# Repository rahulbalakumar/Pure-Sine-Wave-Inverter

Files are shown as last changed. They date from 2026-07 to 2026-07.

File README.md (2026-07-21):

# 300W Pure Sine Wave Inverter - Final Project Repository

## 📋 Table of Contents
1. [Project Overview](#project-overview)
2. [Team Members](#team-members)
3. [Problem Statement & Motivation](#problem-statement--motivation)
4. [Technical Architecture](#technical-architecture)
5. [PCB Design & Schematics](#pcb-design--schematics)
6. [Simulations & Verification](#simulations--verification)
7. [Enclosure & Mechanical Design](#enclosure--mechanical-design)
8. [Bill of Quantities (BOQ) & Costing](#bill-of-quantities-boq--costing)
9. [Manufacturing Considerations](#manufacturing-considerations)
10. [Marketing & Competitor Landscape](#marketing--competitor-landscape)
11. [Future Improvements](#future-improvements)

---

## 🏛️ Project Overview
This repository contains the complete documentation, design files, schematics, simulations, and manufacturing reports for the **300W Pure Sine Wave Inverter** developed by **Group Forge** for the module **EN2160 - Electronic Design Realization** at the Department of Electronic and Telecommunication Engineering, **University of Moratuwa, Sri Lanka**.

The device is engineered to provide clean, grid-quality AC power (230V, 50Hz) from a 12V battery source during power outages, specifically tailored for low-wattage sensitive electronics (such as Wi-Fi routers, laptops, and monitors) without introducing the harmonic distortion, noise, or overheating characteristic of budget-friendly modified sine wave inverters.

---

## 👥 Team Members (Group Forge)

| # | Name | Index Number | Role / Core Responsibilities |
|---|---|---|---|
| 1 | **Athukorala U.R.** | 230063B | Schematics, Hardware Testing, and System Assembly |
| 2 | **De Mel D.J.** | 230121D | Power Stage (12V-400V) Design, Simulation, PCB Design, Assembly & Testing |
| 3 | **Fernando W.H.D.** | 230186E | Enclosure Design, Physical Integration, Testing & Validation |
| 4 | **Rahul B.** | 230508V | Controller Design, Schematics, PCB Routing, Component Selection & Testing |
| 5 | **Ratheeshan A.R.** | 230539P | Controller Schematics, H-Bridge & Filter Simulation, PCB Routing & Testing |

---

## ⚡ Problem Statement & Motivation

### Problem Statement
In Sri Lanka, frequent grid power interruptions severely disrupt day-to-day activities and remote work. While cheap backup solutions exist, budget modified sine wave inverters cause electrical noise, overheating, and long-term degradation in sensitive equipment. There is an urgent need for a cost-effective, highly efficient 300W pure sine wave inverter delivering clean grid-equivalent power.

### Motivation & Statistics
* **Grid Vulnerability:** Over **1 million Sri Lankan households** lost power access during recent energy crunches (2023 data).
* **Daily Blackouts:** Extended load-shedding hours forced households to look for reliable local backup solutions for essential low-wattage devices (<300W).

---

## ⚙️ Technical Architecture

The inverter utilizes a high-frequency two-stage power conversion topology:

1. **DC-DC Boost Stage (12V to 350V DC):**
   * Driven by an **SG3525 PWM controller module** switching primary-side high-current Power MOSFETs.
   * Features a custom hand-wound center-tapped ferrite core transformer (1:40 winding ratio).
   * A full-bridge fast-recovery diode rectifier converts high-frequency AC to a stable 350V DC bus.

2. **DC-AC Inverter Stage (350V DC to 230V 50Hz AC):**
   * Built around the **EG8010 ASIC architecture (EGS002 module)** providing precise SPWM signal generation with hardware dead-time control to prevent shoot-through.
   * Full H-bridge high-voltage MOSFET configuration driven by high/low-side drivers.
   * **LC Low-Pass Output Filter:** Smooths out high-frequency switching edges to yield a pristine 50Hz pure sine wave.
   * **Real-time Feedback Loop:** Continuously monitors output voltage via a resistor divider and feeds data back to the controller to dynamically adjust duty cycles under varying loads.

---

## 🖨️ PCB Design & Schematics

To isolate noisy high-current switching paths from sensitive low-voltage control signals, the hardware is partitioned into **two distinct 2-layer FR4 PCBs (1.6mm thickness, 1oz copper weight, manufactured via JLCPCB)**:

* **Controller Board:** Houses the EG8010 module, 12V-to-5V buck regulators, protection comparator logic, and display headers.
* **Power Board:** Houses the 12V-400V push-pull boost converters, primary-side MOSFET arrays, bridge rectifiers, H-bridge switching stage, and output LC filters.

---

## 📈 Simulations & Verification

Design parameters and passive component selections were rigorously verified using industry-standard simulation tools:
* **LTspice:** Utilized for modeling the SG3525 push-pull boost converter, transformer winding ratios, current draws, and snubber circuits.
* **MATLAB Simulink:** Employed to simulate unipolar SPWM generation, H-bridge switching behavior, and LC filter attenuation to guarantee total harmonic distortion (THD) remains minimal.

---

## 📦 Enclosure & Mechanical Design

* **Material:** Formed from durable **zinc-coated steel**, chosen over mild steel for superior bendability, corrosion resistance, structural rigidity, and natural Faraday cage shielding against electromagnetic interference (EMI).
* **Thermal Management:** Optimized interior layout featuring custom aluminum heat sinks attached to power MOSFETs and a temperature-controlled cooling fan triggered via thermistors.
* **I/O Integration:** Equipped with a 30A mounting post for low-voltage high-current battery inputs, standard 3-pin AC sockets for output appliances, a power toggle switch, and a front-mounted LCD readout screen.

---

## 💰 Bill of Quantities (BOQ) & Costing

### Prototype Cost Breakdown (LKR)
| Item Description / Part Number | Qty | Unit Cost (Rs.) | Total (Rs.) |
|---|---|---|---|
| EG8010 SPWM controller module | 1 | 1,200 | 1,200 |
| SG3525 PWM controller | 1 | 250 | 250 |
| IR2110 high/low-side driver | 2 | 300 | 600 |
| Power MOSFETs (H-bridge + push-pull) | 6 | 350 | 2,100 |
| Ferrite core transformer (custom wound) | 1 | 1,200 | 1,200 |
| LM2678SX-5.0 buck regulator | 1 | 350 | 350 |
| TPS55289 buck-boost converter | 1 | 500 | 500 |
| Bridge rectifier + filter capacitors | 1 set | 850 | 850 |
| LCD display module | 1 | 650 | 650 |
| Connectors, resistors, passives, PCB fabrication | 1 set | 6,000 | 6,000 |
| **Total Prototype Cost** | | | **Rs. 13,700** |

* **Prototype Marginal Cost:** Rs. 14,000.00
* **Absorption Cost (incl. transport):** Rs. 16,000.00
* **Projected Volume Production Cost:** Rs. 10,000.00 – Rs. 13,000.00 per unit (achieving ~20-30% savings on PCBs, enclosures, and bulk component sourcing).

---

## 📊 Market Positioning & Competitor Landscape

| Metric | Our Product (Forge Inverter) | Tier 1 Imported Inverters (Unitec, SAKO, Growatt) | Tier 2 Solar Hybrids (Goodwe, Victron) | Tier 3 Petrol/Diesel Generators |
|---|---|---|---|---|
| **Input** | 12V DC Battery | 12V DC Battery | Solar + Grid | Petrol / Diesel |
| **Advantages** | Clean output, affordable, locally serviceable, 230V/50Hz native | Readily available | Smart monitoring, high capacity | High raw power |
| **Disadvantages** | Early prototype stage | Import markups, 110V/60Hz mismatch issues | Overkill (3-10kW), highly expensive | Loud, heavy, toxic emissions, fuel costs |
| **Price Range** | **Rs. 25,000.00** | LKR 25,000 - 40,000 | LKR 200,000+ | LKR 40,000 - 400,000 |

---

## 🚀 Future Improvements
* **IoT Integration:** Transition from an ASIC-based design to a microcontroller-based architecture with Bluetooth/Wi-Fi telemetry for remote mobile monitoring.
* **Industrial Magnetic Optimization:** Outsource custom transformer winding to industrial facilities to reduce core losses and parasitic inductance.
* **Miniaturization:** Further optimize PCB layouts and surface-mount component placement to reduce weight and overall physical footprint.

---

## 📜 License
This project was developed as an academic submission for the **Department of Electronic and Telecommunication Engineering, University of Moratuwa**. All rights reserved to Group Forge.
README.md
Displaying README.md.

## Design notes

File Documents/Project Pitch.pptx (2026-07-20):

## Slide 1

NO POWER. NO OPTIONS.

A dead battery is the end of the road for every device you own.

TEAM FORGE

WHEN THE GRID GOES DARK, WE DON'T.

POWER, ANYWHERE.

Your 12V battery becomes a full 230V outlet in seconds.

FORGE · 12V → 230V Pure Sine Wave Inverter

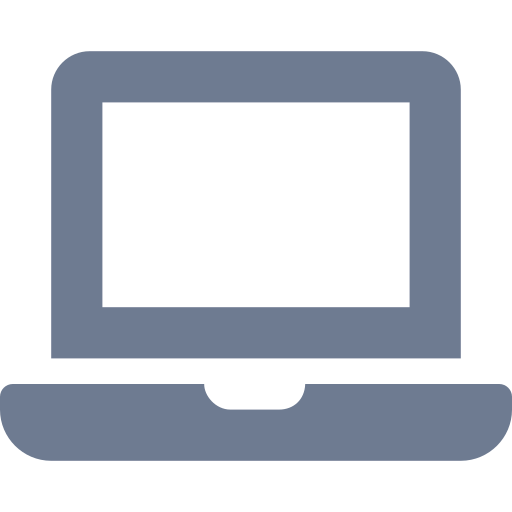
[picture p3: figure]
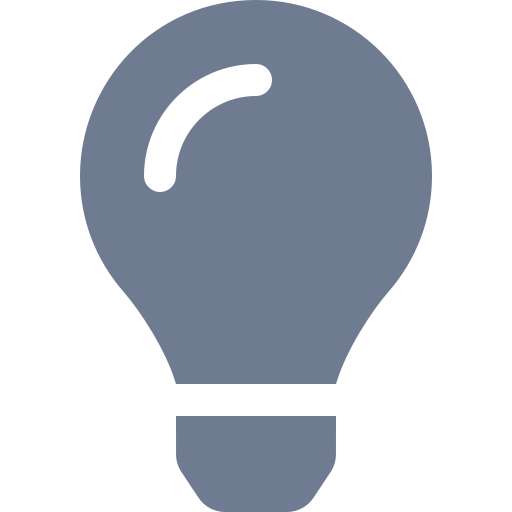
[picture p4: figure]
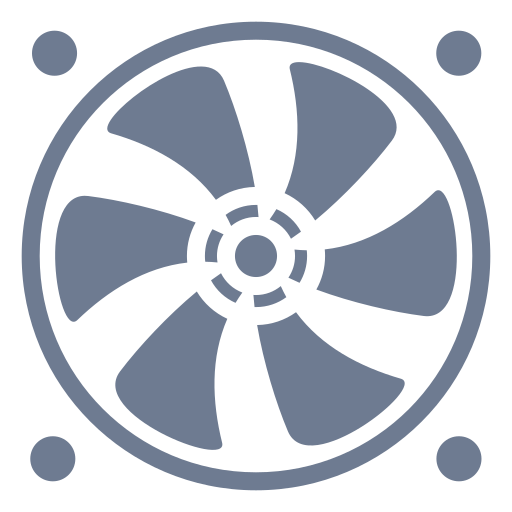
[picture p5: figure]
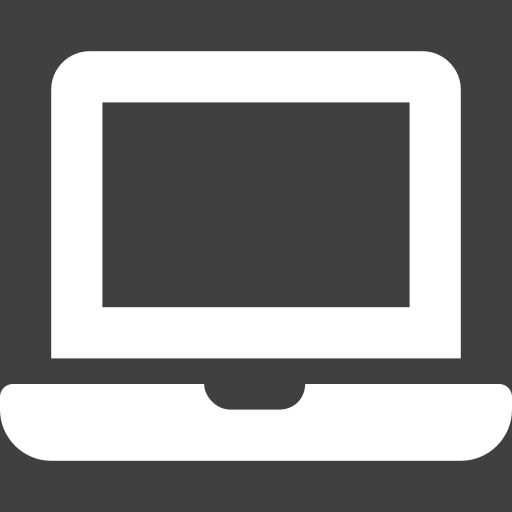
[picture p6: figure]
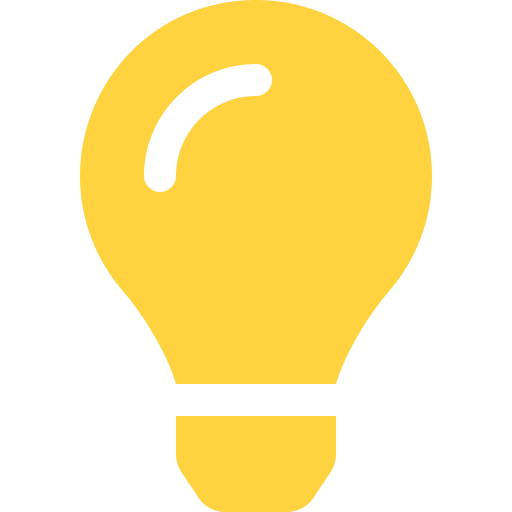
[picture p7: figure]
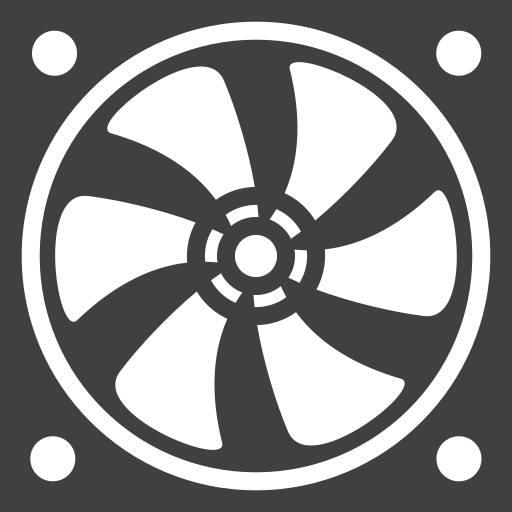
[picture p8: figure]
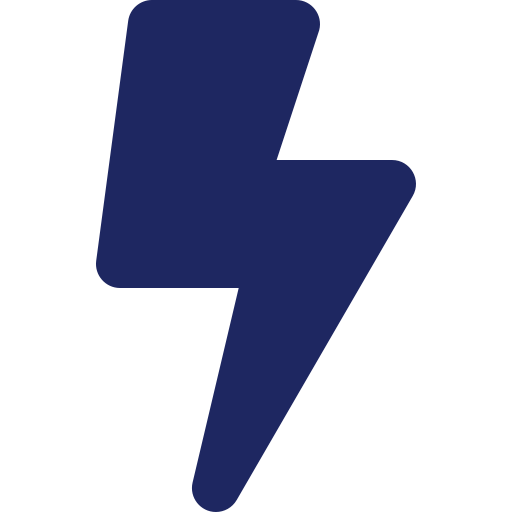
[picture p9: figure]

THE INVERTER

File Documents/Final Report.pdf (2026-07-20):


University of Moratuwa

Department of Electronic and

Telecommunication Engineering

## EN2160 - Electronic Design Realization

# Final Report

## Group Name: Forge

Student Name | Index Number

### 1. ATHUKORALA U R 230063B

2. DE MEL D J | 230121D

### 3. FERNANDO W H D 230186E

4. RAHUL B | 230508V

### 5. RATHEESHAN A R 230539P

## Contents

1 Problem Description, Motivation, and Justification | 3
2 Technical Feasibility | 3
3 Product Architecture | 5
4 PCB Design | 6
5 Product Enclosure | 14
6 Final Product Details | 15
7 Manufacturing Considerations | 17
8 Costing and Pricing | 19
9 Marketing, Sales, and Beyond | 20
10 Project Budget and Bill of Quantities (BOQ) | 21
11 Future Improvements | 21

12 Task Allocation | 22

## 1 Problem Description, Motivation, and Justification

### 1.1 Problem Statement

In Sri Lanka, there are frequent grid power interruptions disrupting the operation of day to day electronic devices. While some affordable backup power solutions exist, most of the budget friendly inverters that currently exist in the market results in problems such as electrical noise, overheating and long term degradation in sensitive equipments. Hence there is a critical need for a cost effective and high efficient pure sine wave inverter that can deliver clean, grid quality AC power using an existing battery to power even the sensitive electrical and electronics during power outages.

### 1.2 Motivation & Survey Results

The motivation stems from severe energy instability experienced all over Sri Lanka in recent years. National grid struggling with capacity constraints, repairings for the grid equipments made reliable access to electricity became a daily challenge for households, disrupting remote work, education and essential communication during disasters.

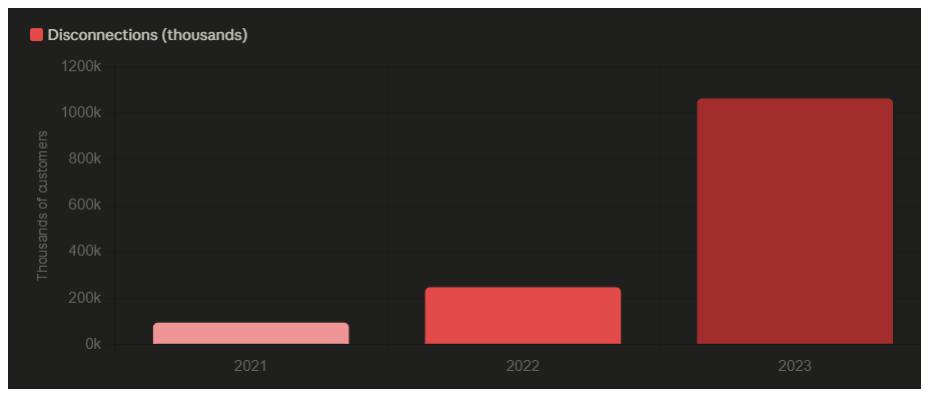
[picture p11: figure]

Figure 1: Over 1 Million Sri Lankan households lost power access in 2023.

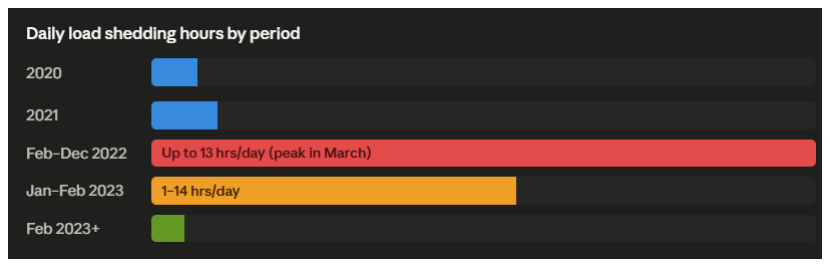
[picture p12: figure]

Figure 2: Scheduled power cut hours per day in Sri Lanka.

As illustrated in Figures 1 and 2, the frequent outages highlights a critical vulnerability for the general houesholds. During these blackouts, users need continuous power for essential, low wattage devices such as Wi-Fi routers, monitors which draw under 300W. While the local market has cheap power backup solutions, those mostly consist of modified sine wave topologies which introduce severe harmonic distortion that causes noise and excessive heat dissipation. Hence these statistics not only confirm the sheer volume of affected households but also validates the specific need for a localized, budget friendly and efficient 300W pure sine wave inverter capable of delivering clean, grid-equivalent power to handle day to day lives.

## 2 Technical Feasibility

We evaluated the technical feasibility of this project in these following domains:

- Control Architecture and SPWM Generation:
For the SPWM generation we had two choices: go with a microcontroller and program it to generate the desired SPWM signals with dead-time controls manually or use an ASIC chip that was custom made for this purpose only. We went with the custom ASIC chip as that would be the most efficient one in terms of power consumption and resources as this was specifically made for this purpose. We chose the architecture of EG8010 which consists of controllable output frequency, dead-time and safety measures for over-voltage and over-current built in.
- Power Stage and Thermal Management:
This part is also covered under the architecture used in EG8010 which uses thermistors in its control loop, to turn on a fan after it reaches a certain temperature threshold. We also used high power MOSFETs with custom heat-sinks attached to it so the heat can be dissipated effectively.
- Component Sourcing and PCB Manufacturing:
All the components are sourced from LCSC with the standard to handle the high power and current requirements. We wound our own ferrite core transformer to accustom to our need. Standard ceramic SMD components were used for non critical components on the PCB. The PCB trace widths are made to withstand the high current and was outsourced from JLCPCB. We made 2 PCBs, one is for the controller board which acts as the brain of the inverter and the other one is the power board which has all the critical high current components on it with the transformer being hoisted on the enclosure outside of the PCBs.
- Testing and Validation Capabilities:

We tested each board seperately, we gave controlled inputs to the control board and observed the SPWM signals generated from the control board, then we connected the controller PCB with the power board with appropriate connections without the transformer and observed a clean pure sine wave at 50 Hz. Then we assembled everything together as one system and connected a standard home appliance checked its performance to ensure our product is working.

## 3 Product Architecture

### 3.1 Block Diagram

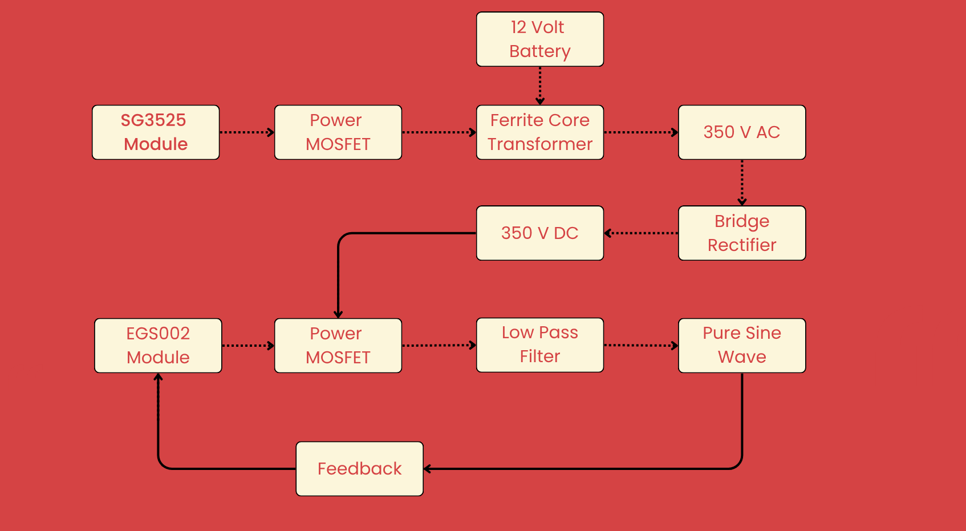
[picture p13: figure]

Figure 3: System Block Diagram showing core functionality.

### 3.2 Component Description & Functionality

Based on the system architecture, the inverter operates using a high-frequency, two-stage power conversion topology. The functionality of each core block is as follows:

- 12 Volt Battery:
Primary DC power source supplying high-current, low-voltage power to the primary side of the transformer.
- SG3525 Module & Power MOSFETs (DC-DC Boost Stage):
SG3525 provides the high frequency PWM drive signals to rapidly switch the primary side Power MOSFETs on and off. This converts the 12V DC into a high frequency square wave.
- Ferrite Core Transformer:
A high frequency custom wound ferrite core transformer which steps up the 12V chopped square wave to a high frequency 350V AC.
- Bridge Rectifier:
Using fast-recovery diodes configured in a full bridge to convert the high frequency AC back to a high-voltage stable 350V DC bus.
- EGS002 Module (SPWM Controller):
Brain of the DC-AC conversion stage built around the EG8010 ASIC architecture, which generates precise SPWM signals with built-in dead-time control to prevent shoot throughs in the final power stage.

- Power MOSFETs (H-Bridge Inverter Stage):
Full H-bridge configuration of high voltage MOSFETs, driven by IR2110 driver to rapidly switch 350V DC bus to generate an AC high-voltage SPWM waveform.
- Low Pass Filter (LC Filter):
The filter to smooth out the high-frequency switching edges of the SPWM signal to convert into a clean 50Hz 230V AC output for sensitive electronics.
- Feedback Loop:
Feedback loop for the voltage consists of a step-down resistor divider using that we continously monitor the final AC output voltage. This data is feedback to the controller board to adjust the SPWM duty cycle in real-time to maintain a stable 230V 50Hz output even when the load changes or the battery drains.

## 4 PCB Design

### 4.1 Schematic and Layout Design

To reduce complexity of the whole system, we divided into two PCBs: a Controller Board and a Power Board. This separation makes sure that the low-voltage control signals are isolated from the high-current, high-voltage switching paths significantly reducing EMI and improving the system stability overall.

Hierarchical Schematic Approach

We followed a hierarchical schematic design approach to reduce clutter when following the schematic for technical reasons. This allows easy debugging and improves readablity.

### 1. Controller Board

The Controller Board houses the low-voltage logic and signal generation components, including the EG8010 chip, alongside the voltage and current feedback conditioning circuits.

- Layout Considerations: We prioritized short traces for high frequency signals and utilized a ground plane for better performance.

### 2. Power Board

This board Contains two main parts, 12V - 400V voltage converter and the Hbridge+Output filter.

4.1.1 12V - 400V convertion

A push pull converter was designed to boost 12V to 400V. It contains the 12V DC input bus, primary-side MOSFETs, DC rectifier and the high voltage H-bridge output stage with the filter.

- The SG3525 was used due to its ability to adjust the duty cycle of its PWM output signal to keep the output voltage (400V) constant under varying load conditions.

This is achieved using a feedback signal obtained by using a voltage divider with a variable resistor.

- The primary winding of the transformer was sized to handle a current of approximately 25A. 24 strands of 0.6mm magnet wire were fashioned into a litz wire.
- Layout Considerations: The appropriate trace widths were used for the high current paths in the primary-side. Strict clearance and creepage distances were maintained for the high-voltage sections to prevent high-voltage arcing. Testing points were used in both boards for quick debugging and testing.

### 4.1.2 Hbridge + Output Filter

This part Converts the 400V DC into 230V sinewave AC.

- Optimized low inductance traces were used for the high voltage DC bus and Hbridge switching nodes to minimize parasitics and to reduce voltage overshoot during MOSFET turn-off.
- The high side and low side MOSFET pairs were placed symmetrically close to the gate driver to keep gate drive loop areas small and minimize switching noise.
- Gate resistors and bootstrap components were placed as close as possible to their respective MOSFET gates and bootstrap diodes to ensure clean, fast switching transitions.
- A solid ground plane was maintained beneath the switching stage to provide a low-impedance return path and reduce EMI coupling into sensitive control traces.
- Strict clearance was enforced around the high-voltage DC bus and switching nodes, to satisfy high-voltage safety margins, also the output LC filter was placed close to the H bridge output to minimize the loop area exposed to high speed switching.

### 1. Controller Board Schematics

The Controller Board houses the low-voltage logic, signal generation components, and isolated power supplies. To manage the design hierarchically, the circuitry is divided into specific functional blocks as shown below.

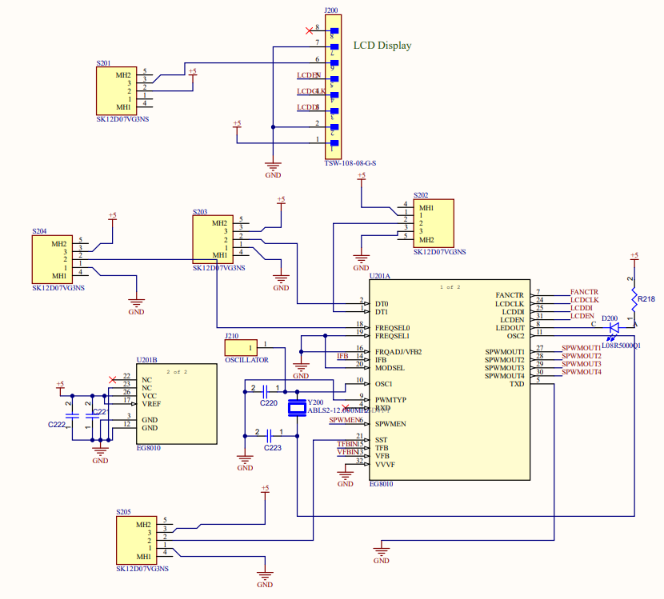
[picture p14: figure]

Figure 4: EG8010 SPWM Controller.

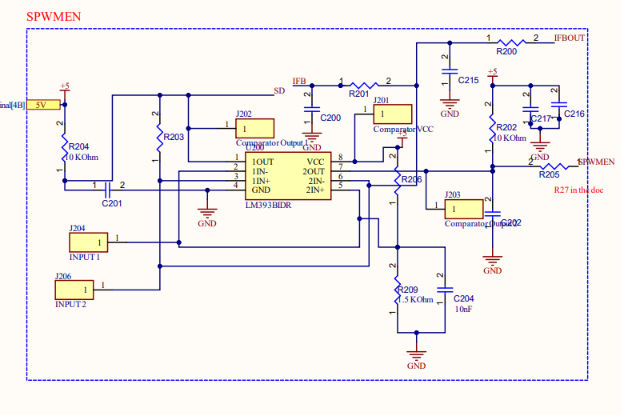
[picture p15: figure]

Figure 5: Comparator / Protection Logic.

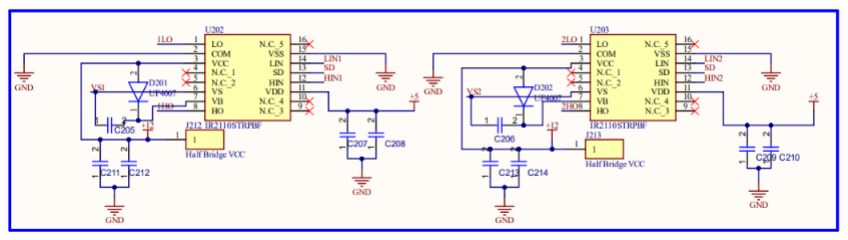
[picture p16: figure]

Figure 6: Gate Driver Circuitry.

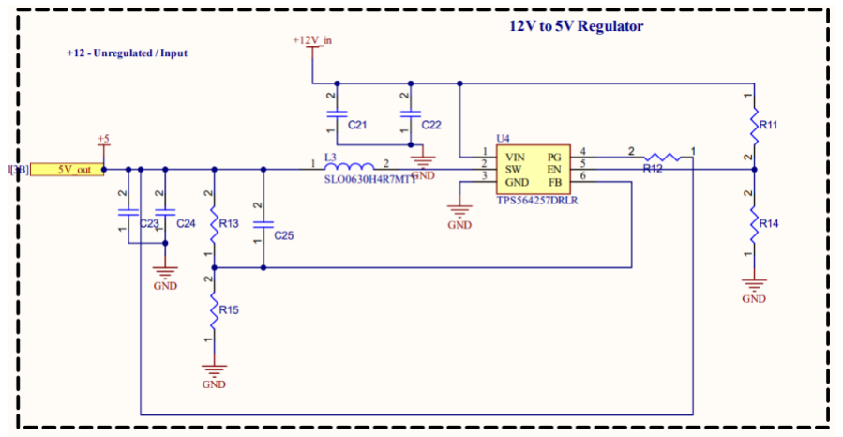
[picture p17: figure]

Figure 7: 12V to 5V Logic Power Supply.

Figure 8: Primary control and logic schematics for the Controller Board.

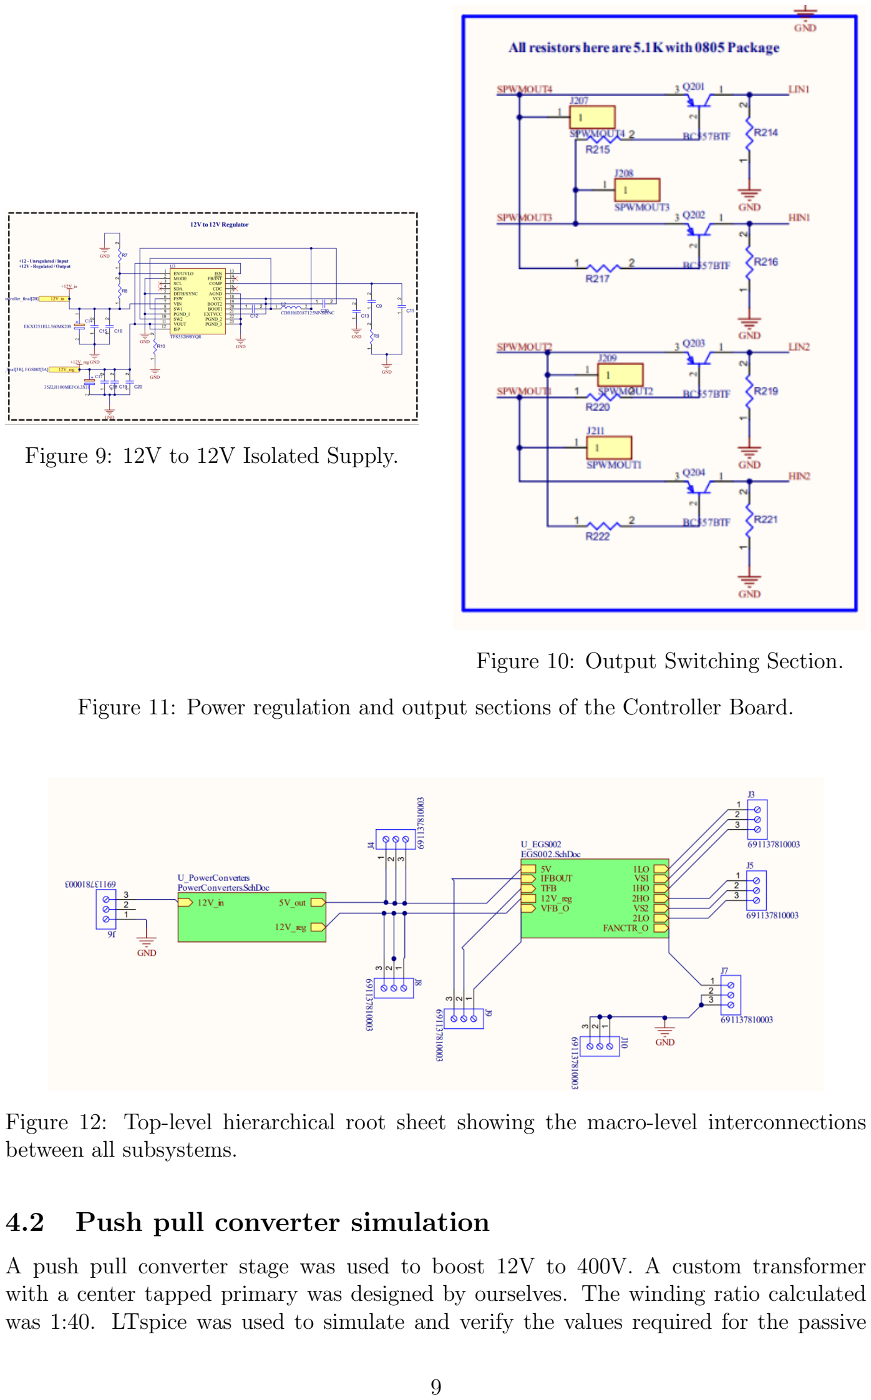
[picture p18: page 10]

Figure 9: 12V to 12V Isolated Supply.

Figure 10: Output Switching Section.

Figure 11: Power regulation and output sections of the Controller Board.

Figure 12: Top-level hierarchical root sheet showing the macro-level interconnections between all subsystems.

### 4.2 Push pull converter simulation

A push pull converter stage was used to boost 12V to 400V. A custom transformer with a center tapped primary was designed by ourselves. The winding ratio calculated was 1:40. LTspice was used to simulate and verify the values required for the passive components(Resistors, capacitors) of the SG3525. Transformer winding ratios, current draw, RC snubber circuits were tested and implemented using the simulations.

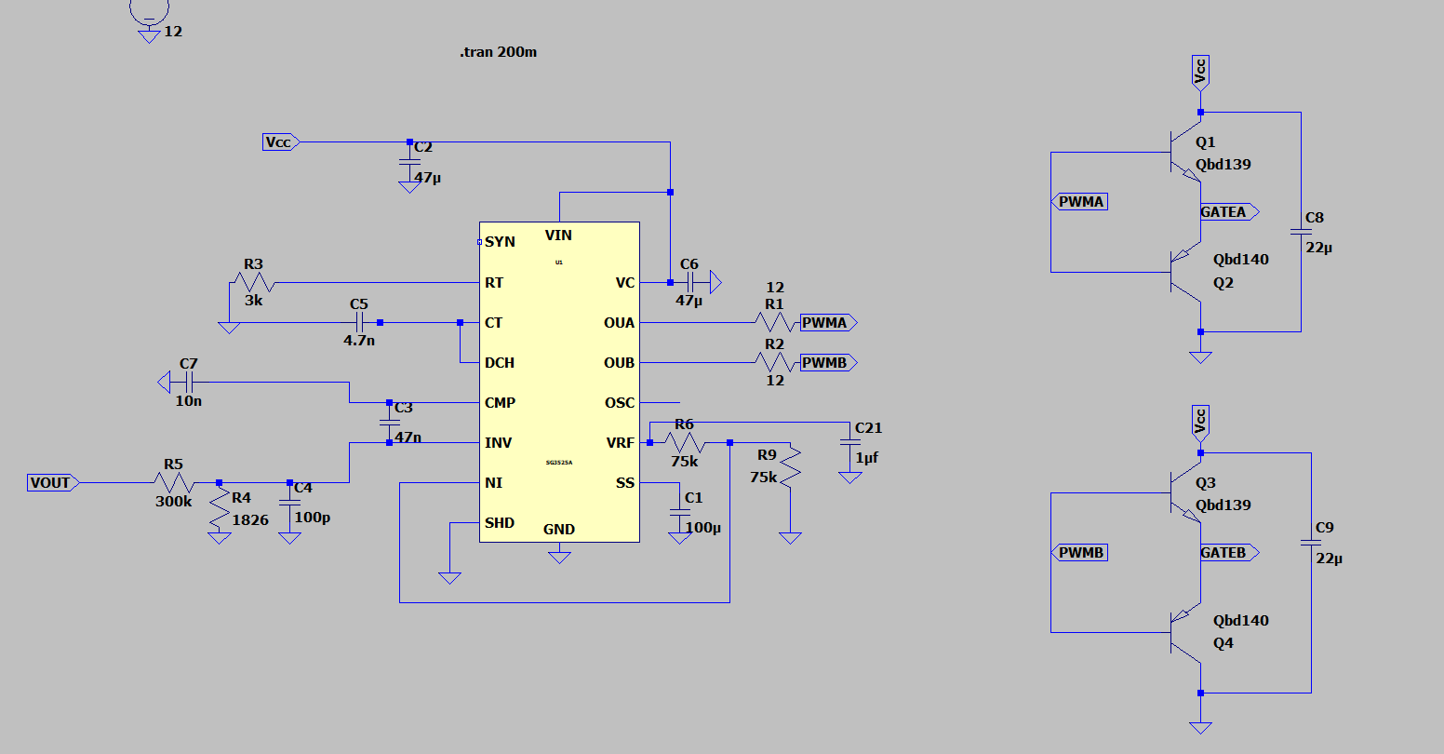
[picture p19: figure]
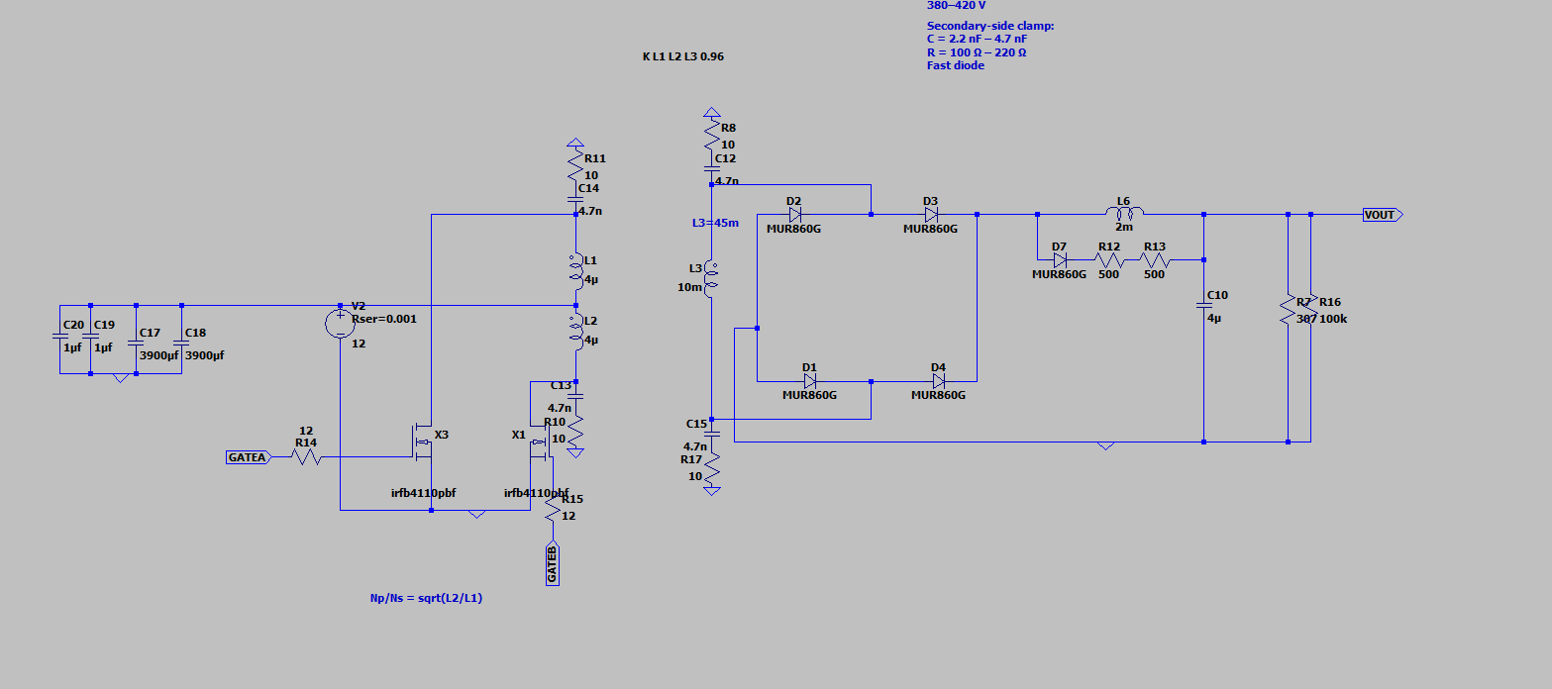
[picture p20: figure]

(a) SG3525 | (b) Transformer

Figure 13: 12V to 400V

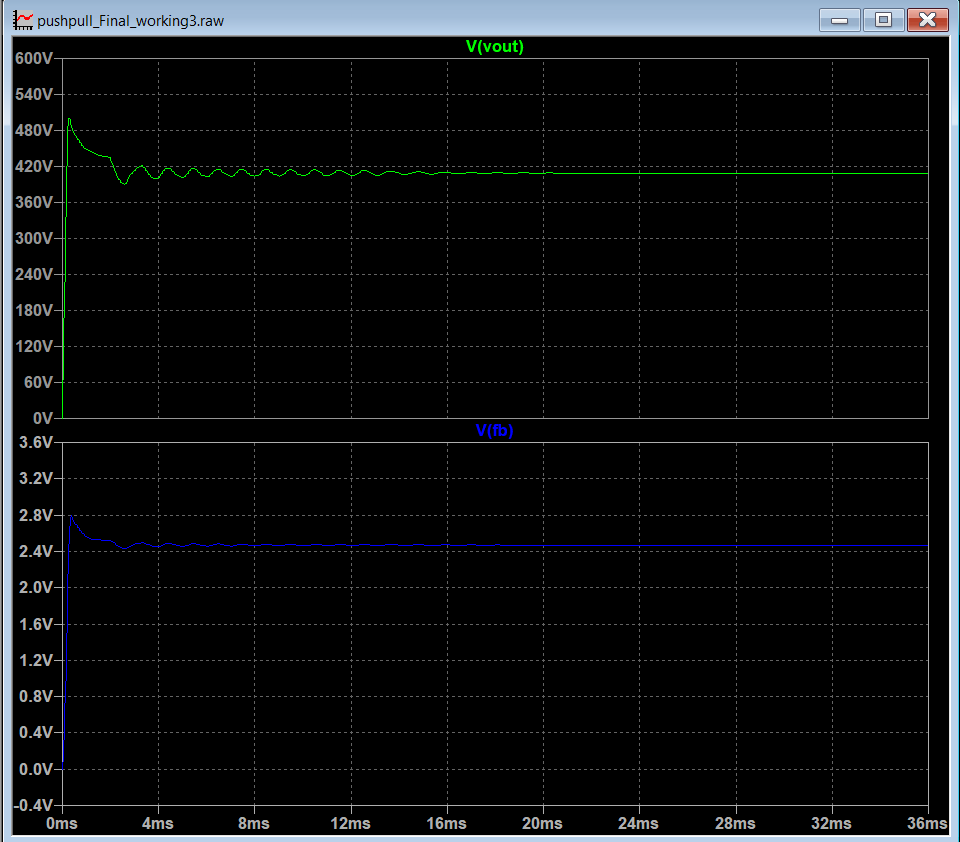
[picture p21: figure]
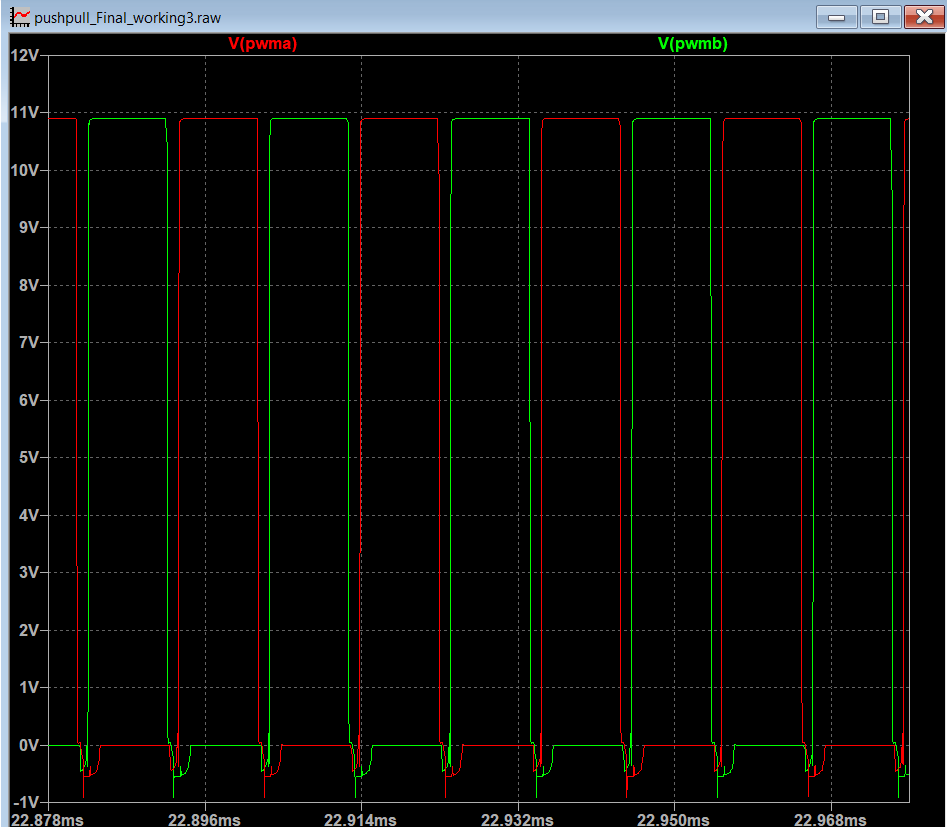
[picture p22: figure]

(a) Mosfet gate drive signals | (b) Output Voltage and Feedback voltage

Figure 14: 12V to 400V

### 4.3 Hbridge & Output simulations

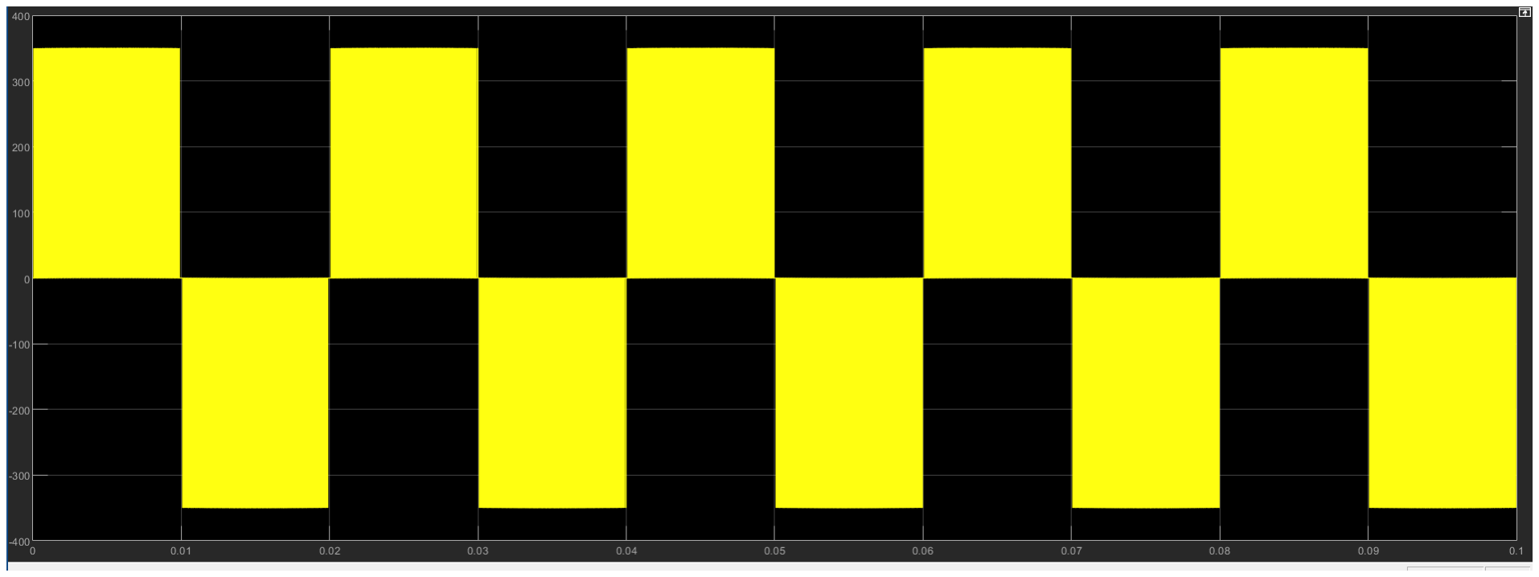
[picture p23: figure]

(a) Unipolar PWM output from the

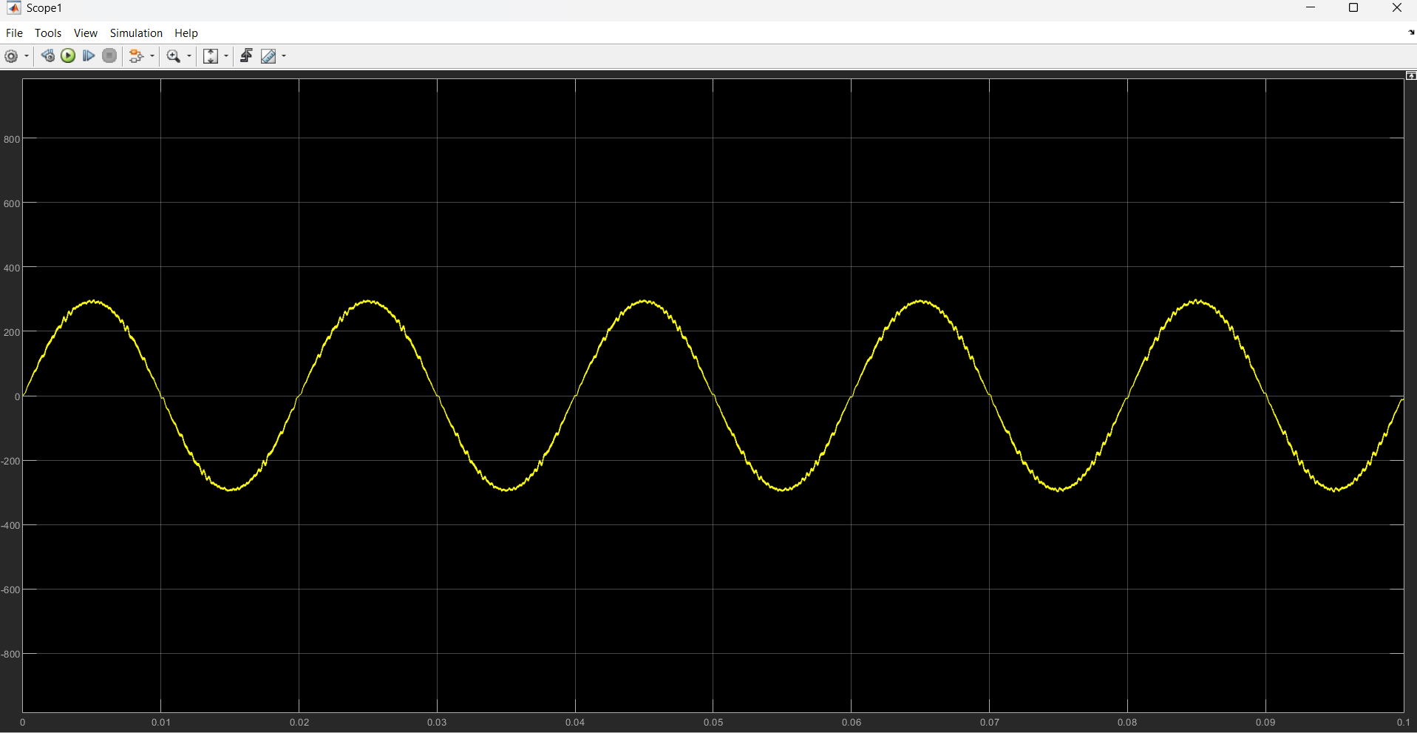
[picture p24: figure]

Hbridge | (b) Final Output Voltage after Filter

Figure 15: 12V to 400V

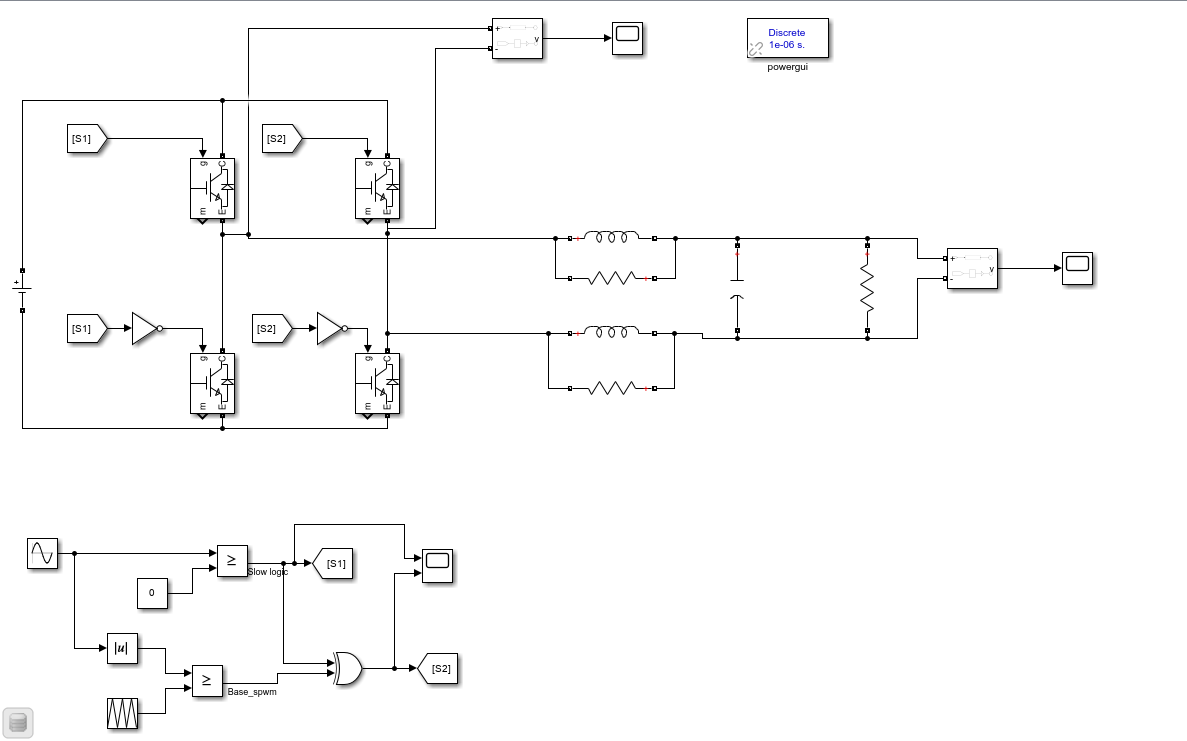
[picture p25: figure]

Figure 16: Simulink model

### 4.4 Power Board Schematics

The Power Board handles the bulk power transfer and voltage conversion. Its hierarchical design is divided into six functional modules to ensure clear signal routing and effective thermal management.

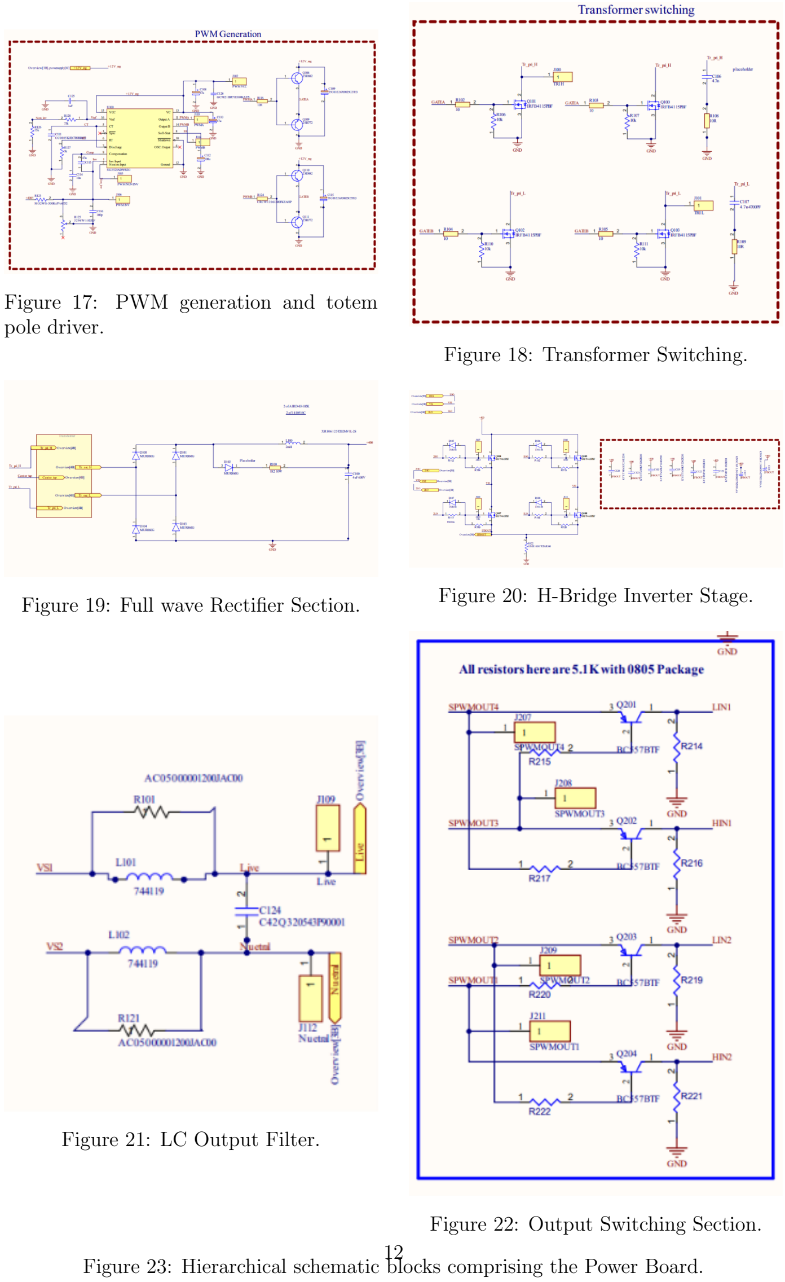
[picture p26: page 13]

Figure 17: PWM generation and totem pole driver.
Figure 18: Transformer Switching.
Figure 19: Full wave Rectifier Section. | Figure 20: H-Bridge Inverter Stage.

Figure 21: LC Output Filter.

Figure 22: Output Switching Section. Figure 23: Hierarchical schematic blocks comprising the Power Board. 12


Figure 24: Power Board Hierarchical Root Sheet.

### 4.5 H-bridge & filter Simulations

Verification of the Bridge implementation and the design and the Component selction for Output Filter was done using MATLAB Simulink.

### 4.6 PCB Stack Justification

Both boards were designed using a standard 2-layer FR4 stack-up with a 1.6mm thickness and 1oz copper weight (JLCPCB).

- Why 2-Layer: A 4-layer board was deemed unnecessary and an overkill for this prototype. To be cost effective we went with 2 layer 2 PCBs.
- Copper Thickness Compensation: While 2oz copper is the ideal one for the high-current boards, we went with the 1oz copper due to budget constraints. But still we utilized appropriate trace widths to increase the current carrying capacity.

## 5 Product Enclosure

### 5.1 Enclosure Design

We designed the enclosure prioritizing thermal management, safety and easy debuggability. Initial design concepts were hand drawn to visualize the placement of the PCBs and other equipments.


Figure 25: Initial conceptual sketch of internal layout.


Figure 26: External port and cooling ventilation design.

Figure 27: Hand-drawn sketches detailing the enclosure architecture.

### 5.2 Finalized Design

The finalized enclosure is designed to house the PCBs, Fan, Transformer , Heat sink and other connecting equipments. They are positioned in such a way that the thermal management is efficient. The enclosure was initially to be made up of mild steel but the metal couldn’t be bent the way the enclosure was designed. So the next choice we went with was zinc coated steel which was perfect to the budget and has good qualities.


Figure 28: Rear view showing terminal and I/O layout.


Figure 29: Front view of the finalized enclosure.

Figure 30: Finalized design of the inverter enclosure.

## 6 Final Product Details

### 6.1 System Overview

The final product integrates both Controller and Power PCBs into a metal enclosure. Here we outline all the important details of the 300W Pure Sine Wave Inverter.

### 6.2 Physical Assembly and Integration

All the components are carefully integrated into the enclosure ensuring electrical safety and optimal thermal performance.

- Board Interconnection: All the boards are connected with appropriate wires matching their specifications (current rating). Thick wires were used to wind the transformer to match our need.
- Component Placement:Inside the enclosure each PCB is mounted on a 3D printed hoist to maximize thermal dissipation and they are seperated via space to ensure isolation between high-voltage sections and low-voltage control sections.
- Mounting and Securing: Square Socket is used to connect home appliances to the inverter. 30A mounting post is used to connect a low-voltage, high-current battery to the input of the inverter. A small switch is used to turn the inverter on. A small mount is fitted to the front side of the inverter to hold the display which will show real-time values.

### 6.3 Bill of Materials and Manufacturing Summary

Details of key components and manufacturing processes used for the final product:

- Active Power Devices: High-current Power MOSFETs, and fast switching diodes were sourced from LCSC which can be bought for a cheaper price when buying in bulk. The center tapped ferrite core transformer is built in house by us to match the needs for this inverter.

- Control Logic Components: EG8010 SPWM generator and SG3525 PWM controller is outsourced from Sri Lanka. SMD versions of the driver modules is outsourced from LCSC as well.
- Fabrication Methods:Two-layer FR4 PCBs x2 is outsourced from LCSC with optimized 1oz copper traces.

### 6.4 System Testing and Validation

Testing was done in parts, the controller board and the power board was tested seperately first then both boards were connected and tested without the inclusion of the transformer, then both boards were tested with the inclusion of the transformer. And as the final test our product was tested with a home appliance to ensure the performance of the inverter.


Figure 31: Mosfet gate drive signals from the SG3525


Figure 32: Top View of the Final Product

## 7 Manufacturing Considerations

### 7.1 Overview

Transitioning from a prototype into a mass production is a whole different ball game. Since our product is a power product it requires rigorous manufacturing and assembling strategies. Special care must be given to high-voltage isolation, heavy-current copper traces and structural integrity of the enclosure.

### 7.2 Custom Transformer Fabrication (In-House Winding)

For the prototype we wound our own transformer matching our needs. For mass production this responsibility can be outsourced to a manufacturer to get high quantity, high quality transformers to be used for manufacturing.

- Core Selection and Preparation: Proper stacking and gluing of the ferrite/laminated iron core to eliminate air gaps where possible and minimize audible buzzing or core vibration under load.

- Wire Gauge (Skin Effect and Current Density): Utilizing multi-strand magnet wire (litz wire technique or bundled enamelled copper wire) for high-frequency windings to mitigate skin effect losses, alongside appropriately rated heavy gauge wire for primary high-current loops.
- Layer Insulation: Application of high-temperature electrical grade insulating tape (e.g., Kapton or Nomex) between primary and secondary layers to guarantee dielectric breakdown strength and prevent high-voltage flashover.
- Tension and Symmetry: Ensuring uniform winding tension to maintain tight coupling coefficients between primary and secondary coils, reducing leakage inductance which otherwise causes damaging voltage spikes on the switching MOSFETs.

### 7.3 Enclosure Fabrication (Zinc-Coated Steel)

The enclosure was fabricated from zinc-coated steel, which can be mass produced by outsourcing to a proper manufacturing company which can provide distinct mechanical and electrical advantages.

- Structural Rigidity and Durability: Zinc coated steel gives good mechanical strenght and protection for heavy internal components and has a good overall structural integrity.
- Corrosion Resistance: The sacrificial zinc layer prevents oxidation and rust formation, ensuring long-term reliability even in humid environments or industrial operating conditions.
- Electromagnetic Interference (EMI) Shielding: The steel acts as a natural faraday cage which significantly reduces EMI from high-frequency switching stages and protecting sensitive equipments.
- Grounding and Safety Integration: The metallic nature ensures proper faultcurrent handling and improves user safety during insulation failures.

### 7.4 PCB Fabrication and Assembly

- Trace Width and Copper Weight:Using 1oz copper layers with expanded polygon pours to safely conduct primary currents without excessive resistive heating.
- Component Placement and Clearance: Maintaining strict physical separation between the low-voltage control circuitry (EG8010 and ICs) and the high-voltage DC/AC switching stages to minimize electromagnetic interference (EMI) coupling. Creepage and clearance distances were intentionally maximized around the 350V DC bus lines.
- Thermal Interface Management:Application of thermal paste to etch the heatsink with the power mosfets to gurantee low thermal resistance.

## 8 Costing and Pricing

### 8.1 Production Cost Analysis

### 8.1.1 Prototype Costing

- Marginal Cost: Rs. 14,000.00
- Absorption Cost: Rs. 16,000.00 (including transport and other non-manufacturing costs)

### 8.1.2 Costing at Volume Production

Based on our analysis of the market and supply chains, unit costs can be reduced through economies of scale as follows:

Table 1: Projected Cost Reduction at Volume Production

Component | | | Cost Reduction
PCB | | | 20%
Enclosure | | | 30%
Other Components | 10%

With these reductions applied at volume, the per-unit product cost can be brought down to Rs. 10,000.00.
Finally, including marketing, manufacturing, and transport costs, the total per-unit cost at volume production would be Rs. 13,000.00.

Table 2: Competitor Landscape

| Tier 1 — Pure Sine
| Wave | Tier 2 — Hybrid
| | Solar | Tier 3 — Genera-
| | | tors
Input | 12V DC battery | Solar + Grid | Petrol / Diesel
Brands | Unitec, | SAKO,
| Growatt, Sorotec
Goodwe, | Huawei,
Victron, | Growatt
| | Hybrid | Yamaha EF, Honda
| | | EU, Local brands
Advantages | Clean | output,
portable, | locally
| available
Solar | integration,
smart | monitoring,
| | long warranty | High power, no bat-
| | | tery needed, widely
| | | available
Disadvantages Import | markup,
| limited local service, 110V/60Hz mismatch
Overkill | (3–10kW),
| | very expensive, fixed
| | install only | Fuel cost, loud, heavy,
| | | exhaust emissions
Price Range | LKR 25,000–40,000 | LKR 200,000+ | LKR 40,000–400,000

Our product has direct competition with Brands like Unitec, SAKO, GOrowatt, Sorotec. But since these brands are imported they have a tax, also less reliable services and voltage and frequency mismatches. Other inverters available in the market are overkill for our target customers with regard to power requirement, features and very expensive.
Hence We are pricing our product at Rs25,000.00.
Profit margin of RS.12,000.00

## 9 Marketing, Sales, and Beyond

Our product positions itself as a low power Pure sine wave inverter, We target customers who need electricity for basic needs when the grid is down and customers require electricity at off grid places. 300W power level makes the product more affordable than the high power inverters and since this is a pure sine wave AC output it’s save to connect sensitive equipments such as laptops.

- House Owners
- Vehicle Owners
- Small business
- Hikers and Campers

Acquiring Customers With the frequent power cuts in the country, demand for inverters is already high. Hence we do a marketing campaign doing advertisements highlighting Low power requirements, affordability and Sri lankan made design and manufacturing. In the early stages of the product launch we offer discounts and renting services to get customers interested. Also getting a local brand ambassadors such as a youtuber related to electric appliances. We are also planning to approach local companies like hayleys electronics once we obtain considerable market share.
Warrenty period of 1 year, and two free services for the inverter will be provided.

## 10 Project Budget and Bill of Quantities (BOQ)

Table 3: Bill of Quantities (BOQ) for Prototype

Item Description / Part Number | Qty | Unit Cost (Rs.) Total (Rs.)
1 | EG8010 SPWM controller | 1 | 1,200 | 1,200
2 | SG3525 PWM controller | 1 | 250 | 250
3 | IR2110 high/low-side driver | 2 | 300 | 600
4 | Power MOSFETs (H-bridge + push-
pull)
6 | 350 | 2,100
5 | Ferrite | core | transformer | (custom
wound)
1 | 1,200 | 1,200
6 | LM2678SX-5.0 buck regulator | 1 | 350 | 350
7 | TPS55289 buck-boost converter | 1 | 500 | 500
8 | Bridge rectifier + filter capacitors | 1 set | 850 | 850
9 | LCD display module | 1 | 650 | 650
10 | Connectors, resistors, misc. passives | 1 set | 6,000 | 6,000
Total Prototype Cost | Rs. 13,700

## 11 Future Improvements

### 11.1 Overview

While our product satisfies the purposes of a minimum viable product, it can be further enhanced by using these:

### 11.2 Potential Enhancements

- Advanced Control and Monitoring: Instead of using an ASIC we can use a micro-controller with Bluetooth / Wi-Fi capabilities to make our product smart to transition into an IoT device.
- Magnetic Component Refinement: By manufacturing the transformer in an industrial setting, we can optimize the loss caused by the transformer.
- Thermal and Weight Reduction: The PCB layout and the enclosure design can be further optimized to reduce the overall size and weight of the device to make it more compact and carry-able.

## 12 Task Allocation

Team Member | Assigned Tasks & Responsibilities

ATHUKORALA U R Schematics, Testing and Assembly
DE MEL D J | Power Stage(12V-400V) design, simulation and schematics, PCB
| design, Assembly and Testing
FERNANDO W H D Enclosure design, Assembly and Testing
RAHUL B | Controller Design & Schematics, PCB design and routing, Com-
| ponent Selection, Assembly and Testing
RATHEESHAN A R | Controller Design & Schematics and H-bridge & Filter simula-
| tion, PCB design and routing, Assembly and Testing

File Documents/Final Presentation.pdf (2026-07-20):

FORGE

# TECHNICAL FEASIBILITY

### Component availability

SG3525, EG8010, IR2110, MOSFETs and the ferrite core transformer are all sourced from established local/regional suppliers within budget — no custom or hard-to-source parts.

### Power target is achievable

300W continuous output is well within the rated capability of the chosen MOSFETs and transformer design, based on datasheet ratings and the push-pull topology selected.

### Efficiency target is realistic

85–95% efficiency is consistent with ferrite-core high-frequency conversion (vs. lossier iron-core alternatives), matching results reported for comparable SG3525/EG8010-based designs.

### Thermal budget is manageable

Estimated 30–45W heat dissipation at full load is handled by the combined active (fan) + passive (heatsink) cooling built into the enclosure design.

### Team skillset is in place

The group has hands-on experience across PCB design, power electronics and CAD enclosure design from prior coursework, covering every stage of this build.

05

FORGE

# FINAL PRODUCT DETAILS

INPUT | 12V DC


OUTPUT | 230V AC, 50Hz pure sine wave
RATED POWER | 300W continuous
EFFICIENCY | 85% – 95%
BATTERY LIFE | N/A — runs off an external 12V source, not a built-in battery. Example: a 60Ah source at 150W load gives ~4 hrs runtime.
PROTECTION | Over-current, over-voltage, reverse polarity

17

FORGE

# PCB LAYOUT & STACK JUSTIFICATION

## Power Supply + H-Bridge Board

2-layer, 2oz copper

Heavier copper and wide traces on the H-bridge / push-pull paths to carry high current with minimal I²R loss.

A dedicated ground plane improves thermal spreading and reduces switching noise.

350V DC and mains-side traces kept with generous clearance from low-voltage control lines for safety.

## Controller (Brain) Board

2-layer, 1oz copper

Signal-level currents only (EG8010 SPWM generation, feedback, LCD) — a lighter 1oz layer keeps cost down.

Two layers give enough routing room for the SPWM/feedback nets without needing a 4-layer stack.

Kept physically separate from the power board per the hierarchical design, isolating noisy switching from sensitive control signals.

22

FORGE

# PROJECT BUDGET — BILL OF QUANTITIES

Approx. breakdown of the Rs. 8,000 components budget (per unit)

Item | Qty | Unit Cost (Rs.) | Total (Rs.)
EG8010 SPWM controller | 1 | 1200 | 1200
SG3525 PWM controller | 1 | 250 | 250
IR2110 high/low-side driver | 2 | 300 | 600
Power MOSFETs (H-bridge + push-pull) | 6 | 350 | 2,100
Ferrite core transformer (custom wound) | 1 | 1,200 | 1,200
LM2678SX-5.0 buck regulator | 1 | 350 | 350
TPS55289 buck-boost converter | 1 | 500 | 500
Bridge rectifier + filter capacitors | 1 set | 850 | 850
LCD display module | 1 | 650 | 650
Connectors, resistors, misc. passives | 1 set | 6,000 | 6,000
TOTAL | | | 13,700

27

FORGE

# FUTURE IMPROVEMENTS

## Bluetooth/Wi-Fi monitoring app for real-time voltage, current and power tracking

## Higher power variants (500W–1000W) for wider appliance compatibility

## Integrated MPPT solar charge controller for direct solar-to-AC operation

## Smaller, lighter enclosure through a higher switching frequency (reduced magnetics size)

## Low-voltage battery cutoff with a clearer charge-level indicator

## Third-party safety certification (e.g. CE/local standards) ahead of volume production

28

FORGE

# TASK ALLOCATION

ID Number | Task Allocation
230063B | Schematics, Testing and Assembly
230121D | Power Stage simulation and schematics, PCB design, Assembly and Testing
230186E | Enclosure design, Assembly and Testing
230508V | Controller Schematics, PCB design and routing, Component Selection, Assembly and Testing
230539P | Controller Schematics and H-bridge & Filter simulation, PCB design and routing, Assembly and Testing

29

FORGE

# THANK YOU

## FORGE — 12V to 230V Pure Sine Wave Inverter

University of Moratuwa · Department of Electronic and Telecommunication Engineering
31

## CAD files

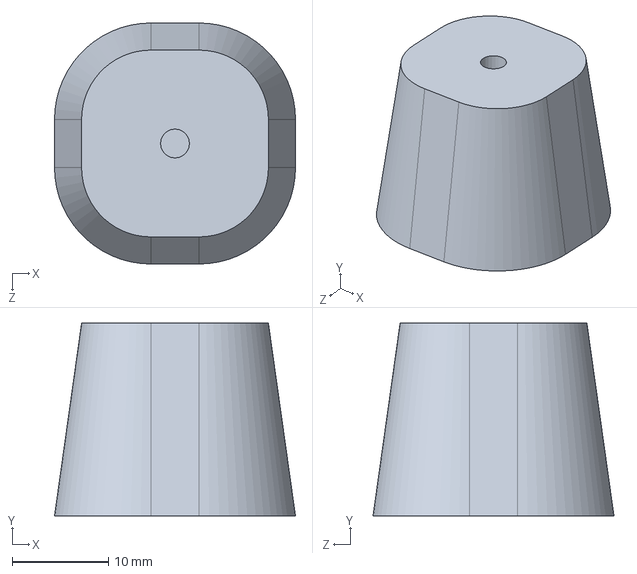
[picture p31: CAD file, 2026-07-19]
Enclosure/pcb_mounts.SLDPRT
25.0 x 20.0 x 25.0 mm

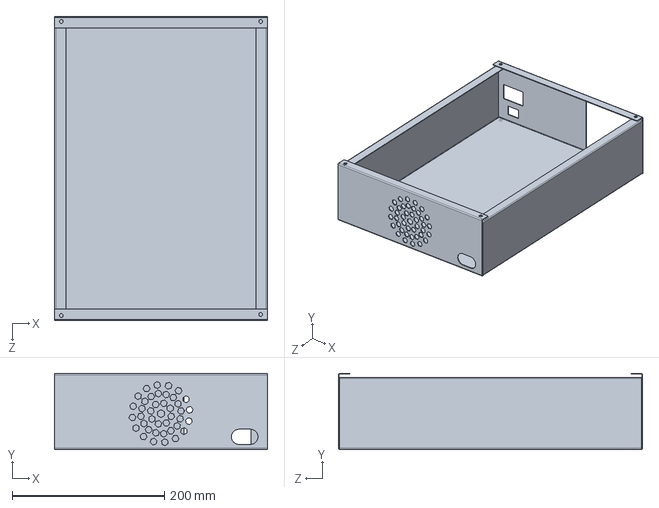
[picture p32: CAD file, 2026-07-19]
Enclosure/forge_bottom.SLDPRT
280.0 x 100.0 x 400.0 mm

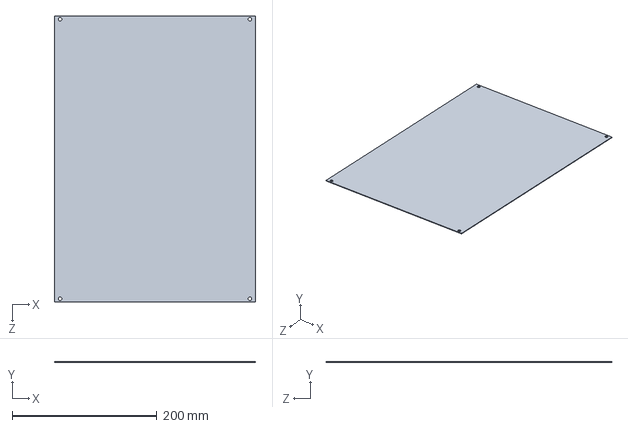
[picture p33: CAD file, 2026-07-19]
Enclosure/top_lid.SLDPRT
278.0 x 1.00 x 395.0 mm

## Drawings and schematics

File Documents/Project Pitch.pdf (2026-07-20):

# T E A M F O R G E

WHEN THE GRID GOES DARK, WE DON'T.

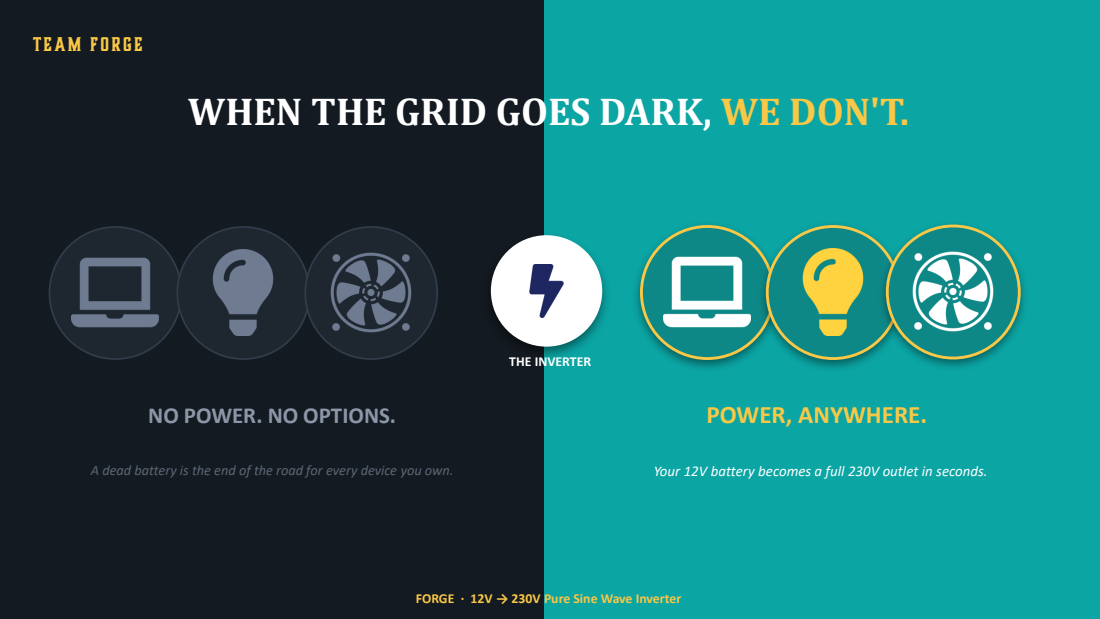
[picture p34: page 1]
POWER, ANYWHERE.; THE INVERTER

NO POWER. NO OPTIONS.

A dead battery is the end of the road for every device you own.

Your 12V battery becomes a full 230V outlet in seconds.

FORGE · 12V → 230V Pure Sine Wave Inverter

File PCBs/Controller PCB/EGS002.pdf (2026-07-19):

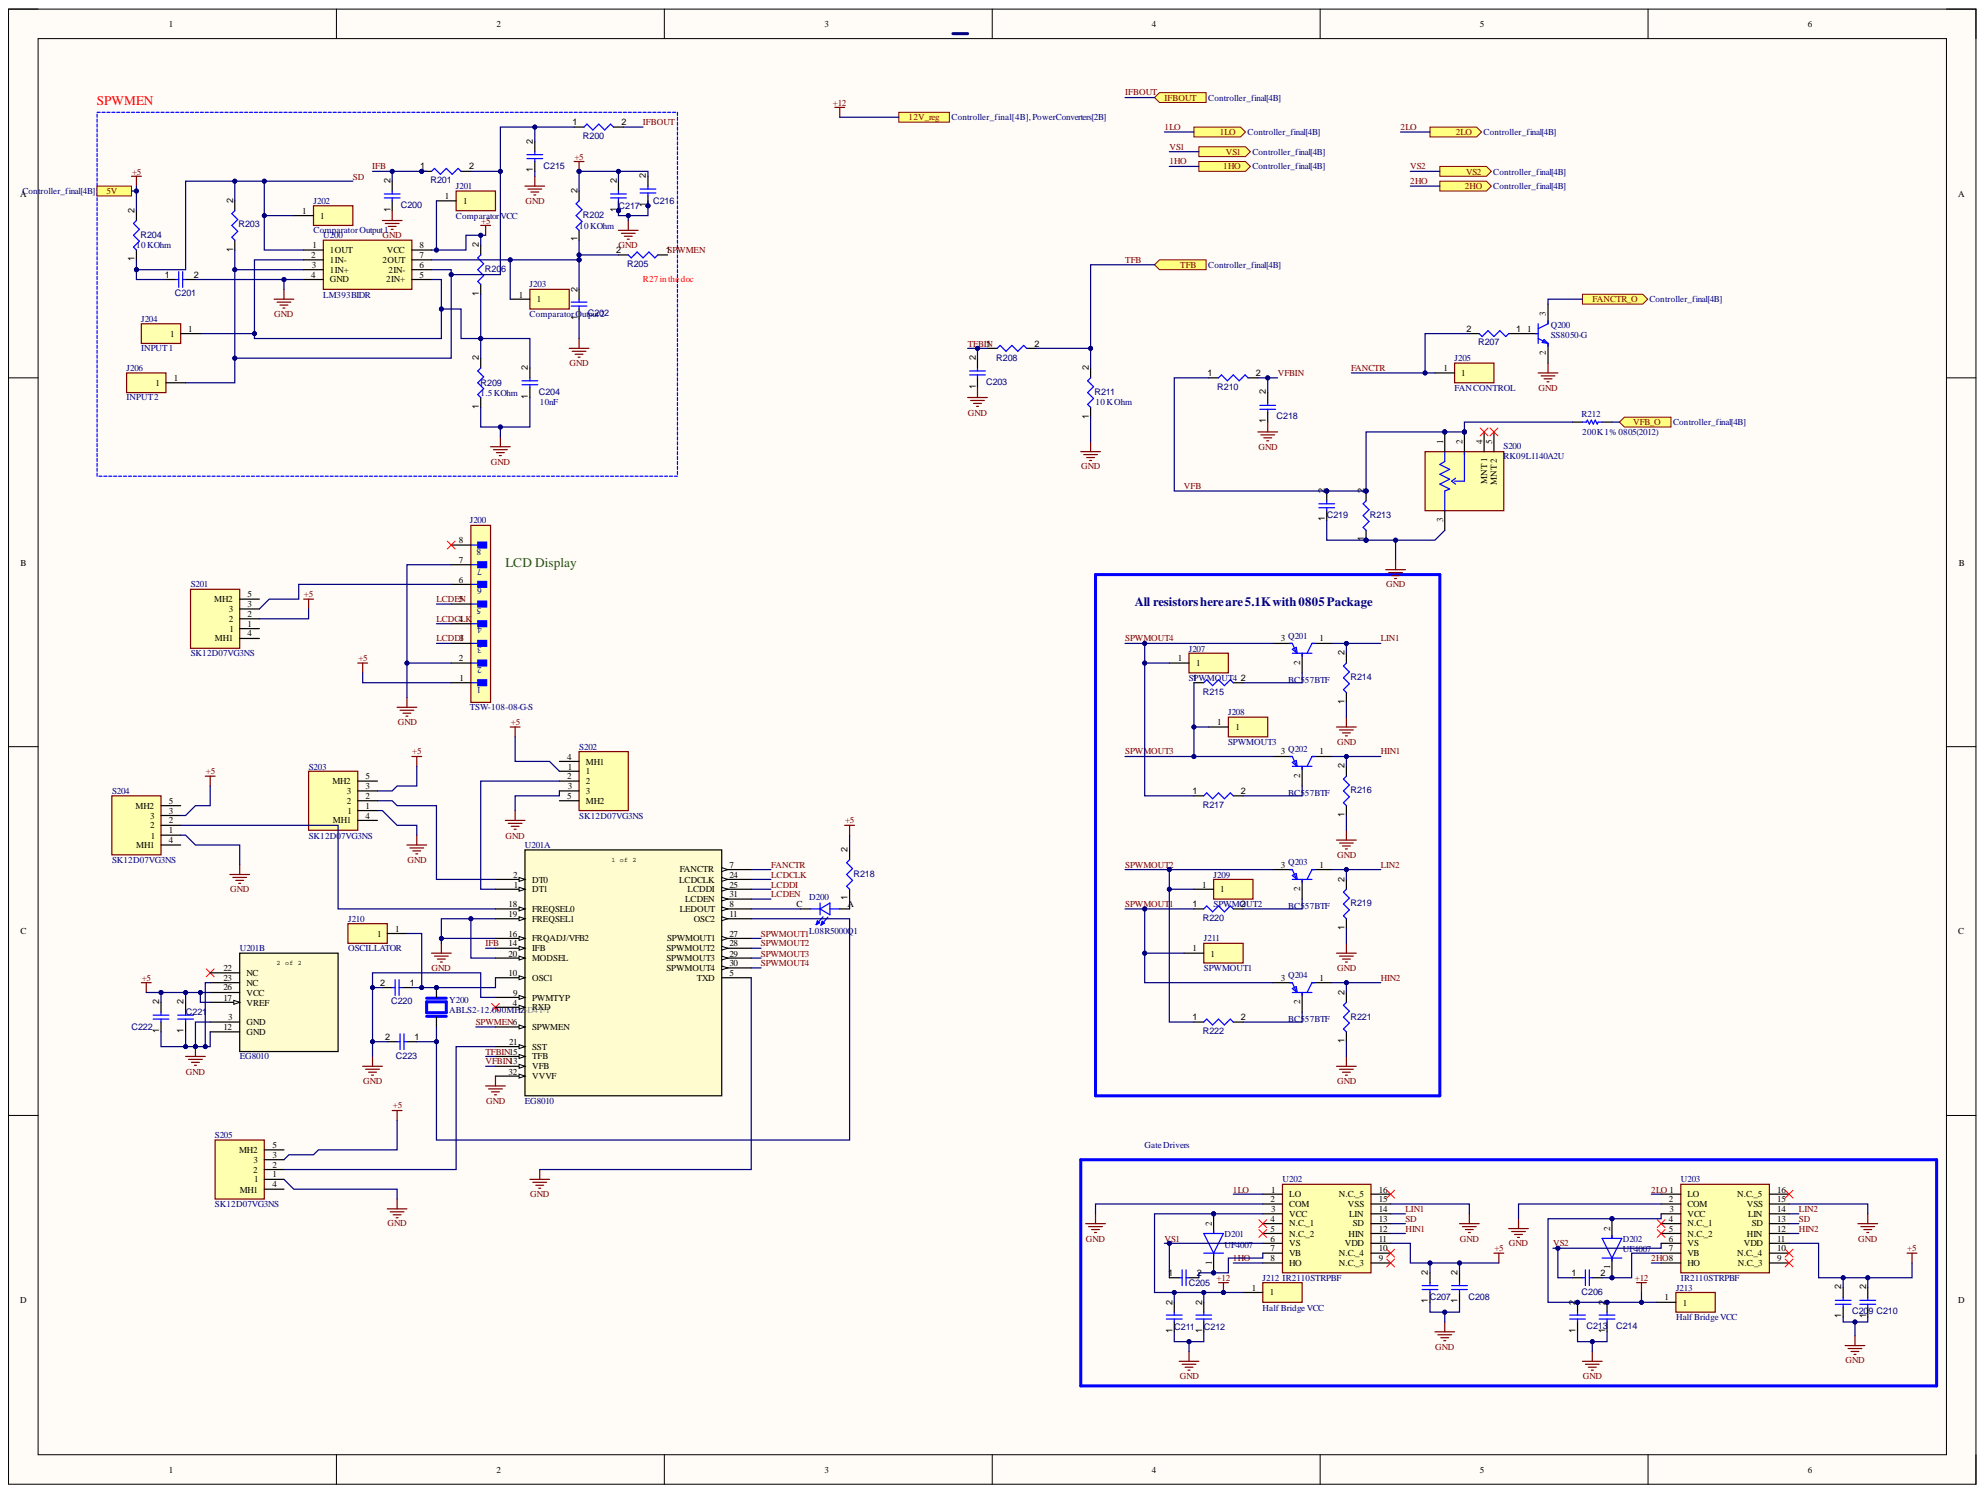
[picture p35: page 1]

10 KOhm

GND 4

All resistors here are 5.1Kwith 0805 Package

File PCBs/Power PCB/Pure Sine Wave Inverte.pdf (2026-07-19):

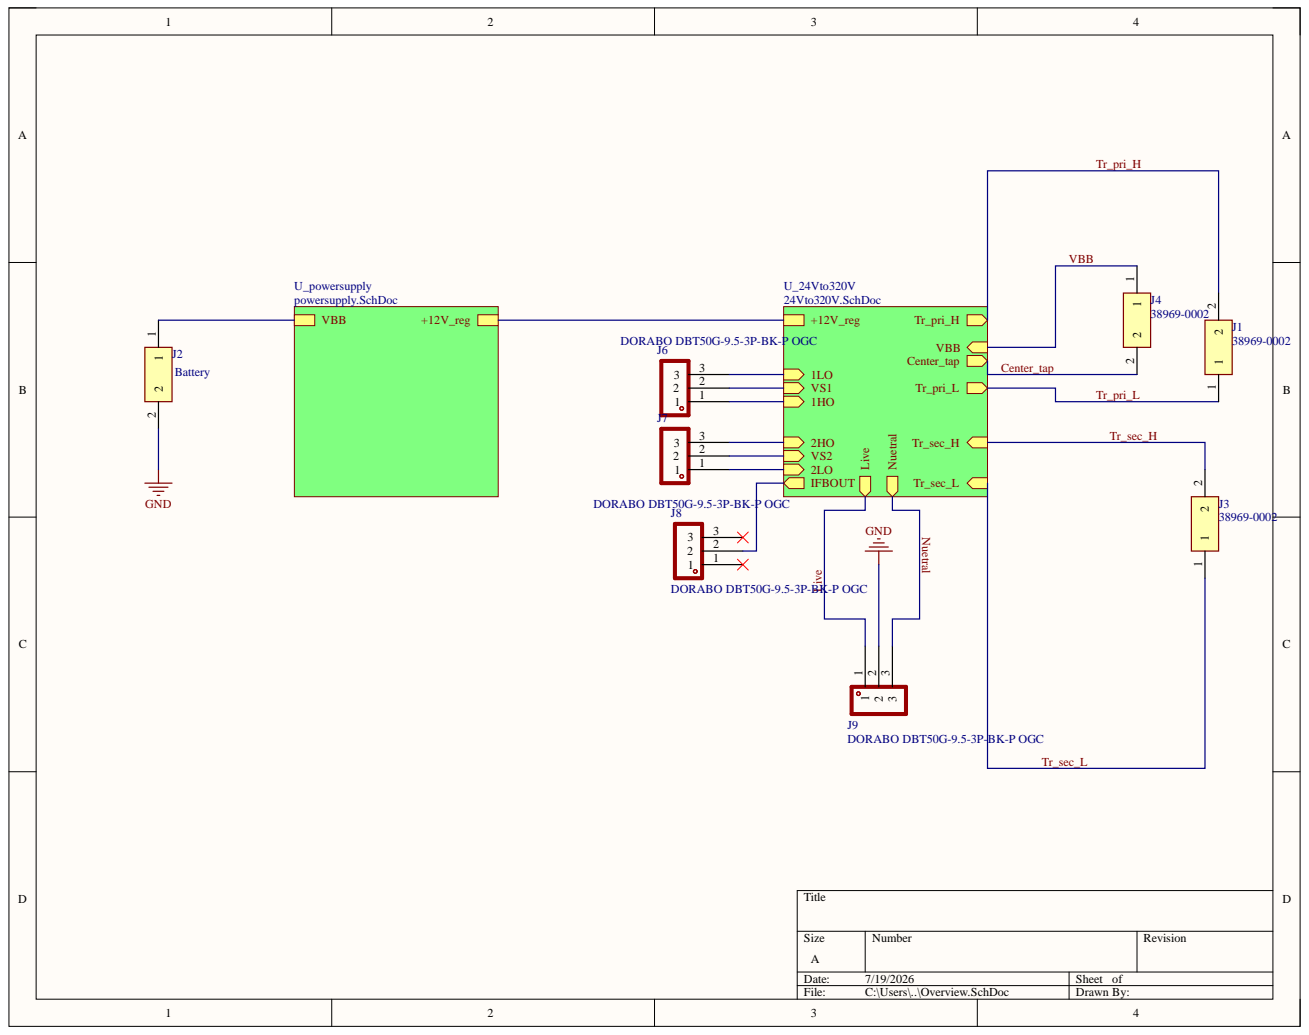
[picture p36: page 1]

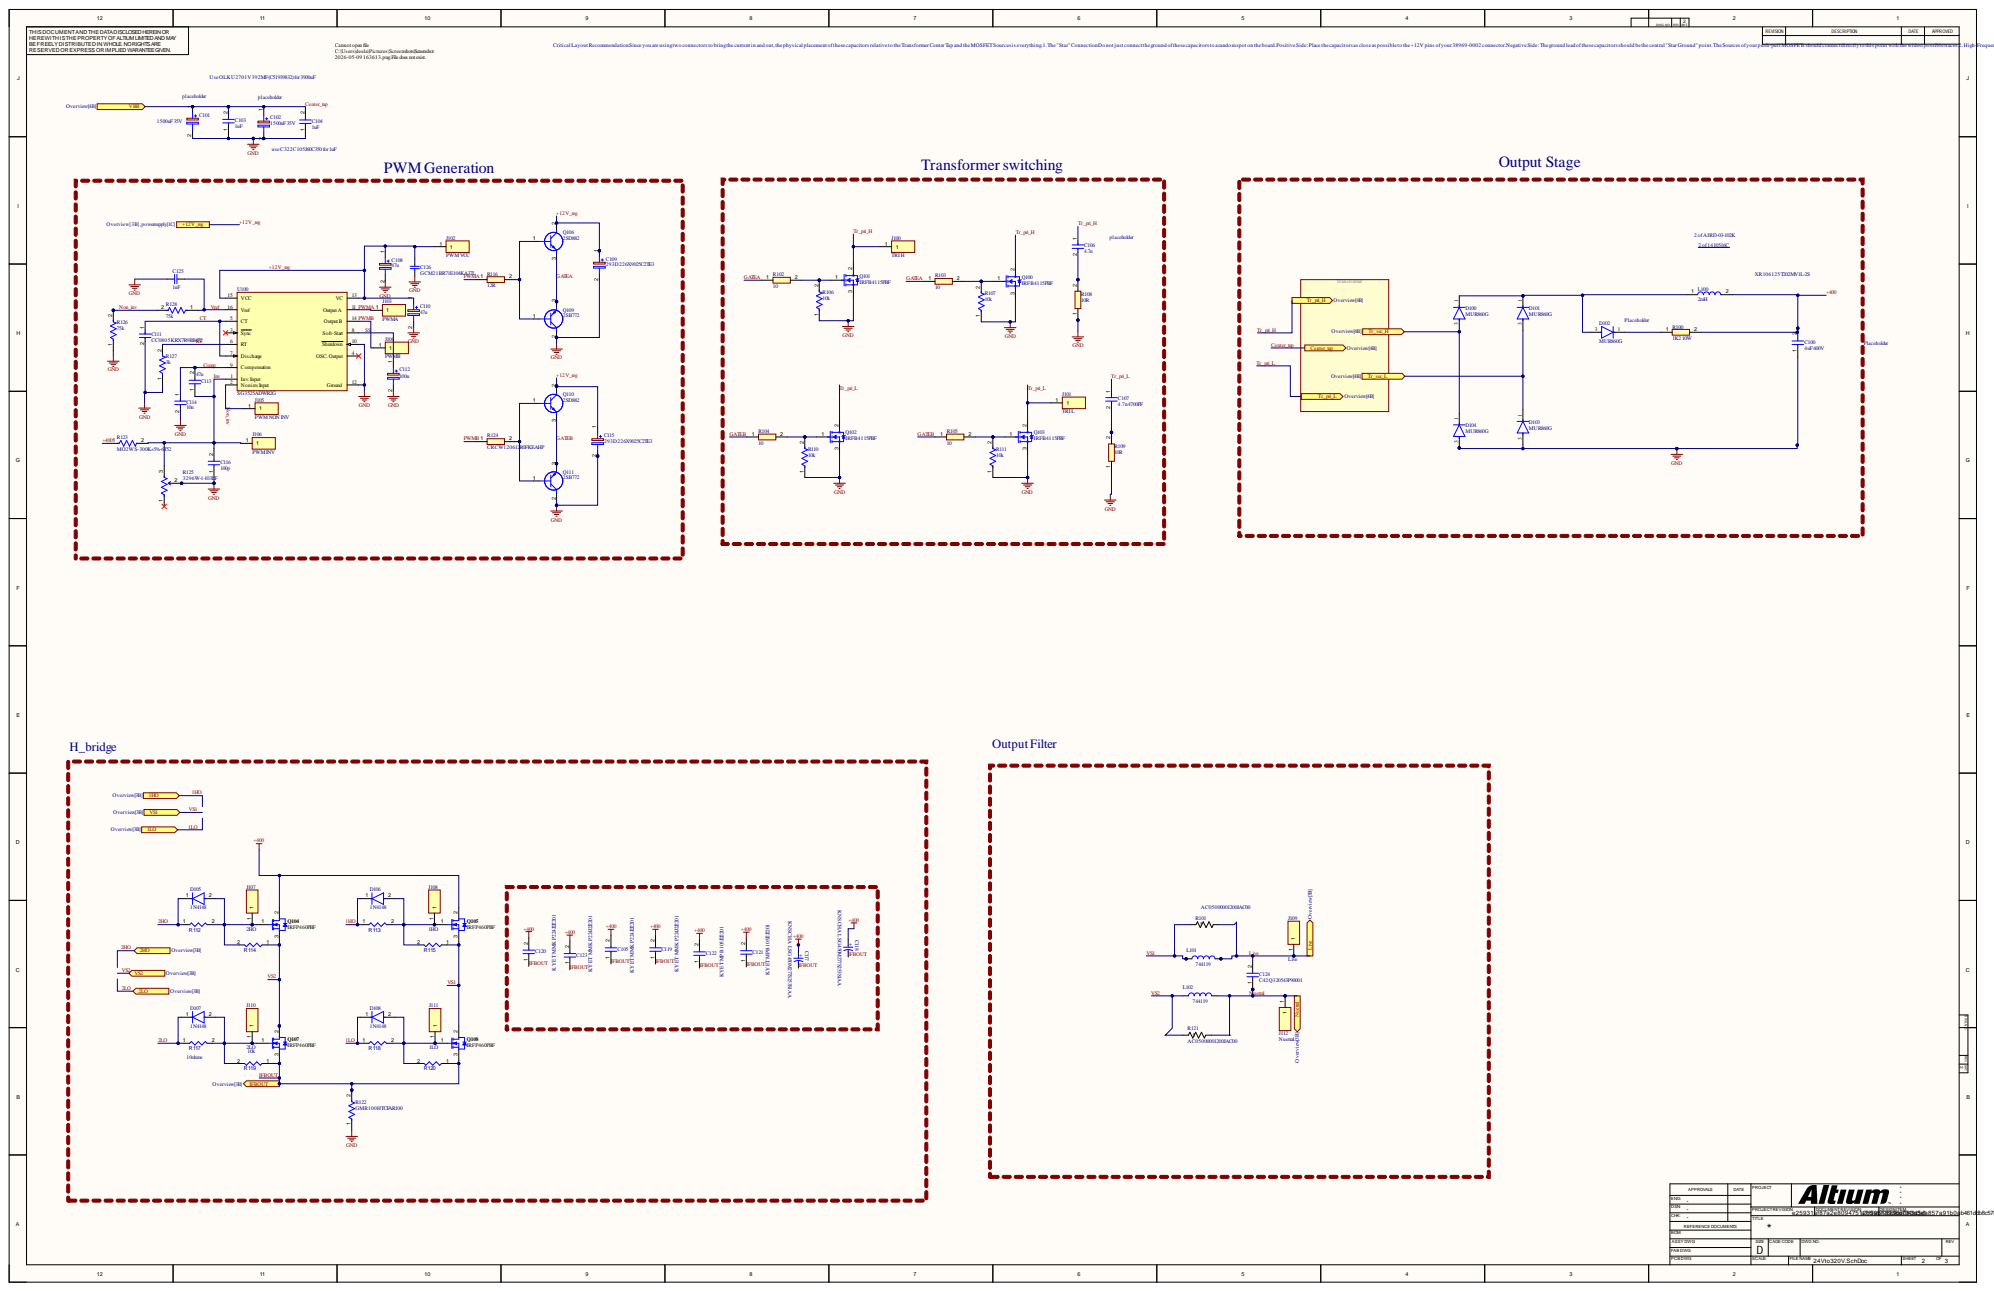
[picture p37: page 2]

DWG.NO. REV. SHT.

THIS DOCUMENTAND THE DATA DISCLOSED HEREIN OR
HEREWITH IS THE PROPERTY OFALTIUM LIMITED AND MAY BE FREELY DISTRIBUTEDIN WHOLE. NO RIGHTS ARE

Cannot open file
C:\Users\deela\Pictures\Screenshots\Screenshot 2026-05-09 163613.png.File does not exist.

CriticalLayoutRecommendationSince you are usingtwo connectorsto bringthe current in and out,the physical placement of these capacitorsrelative to the Transformer Center Tap and the MOSFETSourcesis everything.1.The "Star"ConnectionDo not just connectthe ground of these capacitorsto a random spot on the board.Positive Side: Place the capacitors as close as possible to the +12V pins of your 38969-0002 connector.Negative Side:The ground lead of these capacitorsshould be the central "Star Ground" point.The Sources of your push-pull MOSFETsshould connect directly to this point with the widest possible traces.2.High-FrequencyCapPlacementWhile the $3900\mu\text{F}$ caps can be a fewcentimeters away,the $1\mu\text{F}$ capacitors(C103,C104) should be soldered as close to the MOSFETDrains and the Transformer Center Tap as humanly possible.This minimizesthe loop area,which reducesthe voltage spikesthat can kill your MOSFETs.What’s Missing? (Recommendations)To make this 500W setup truly robust,consider these two additions:SmallCeramic Caps($100\text{nF}$):Add a $100\text{nF}$ (0.1$\mu\text{F}$) X7R ceramic capacitor in parallel with each $1\mu\text{F}$ cap.Ceramics have even lower ESL and handle the nanosecond-scale ringingbetter than film caps.Fuse: At 500W from 12V,you are pullingover 40A.A 60A automotive bolt-down fuse (MIDI or MEGA fuse) should be placed between the battery and $V_{BB}$.If a MOSFETfailsshort-circuit(which is common duringtesting),your traces will vaporize without a fuse.Pro-tip for your EE55 build: Since you mentioned the transformer is external,the inductance of the wires connectingto the center tap willfight the capacitors.Try to keep the $V_{BB}$ line and the Ground line twisted together asthey travel to the transformer to minimize that "stray" inductance.

RESERVEDOREXPRESS ORIMPLIED WARANTEE GIVEN.

Compensation 9 | PWMB

REV. SHT. DWG.NO.

ENG: *

DATE | PROJECT | * * APPROVALS * *
DSN: * CHK: * REFERENCE DOCUMENTS | PROJECTREVISION: DOCUMENTREVISION: DESIGN ITEM: TITLE *

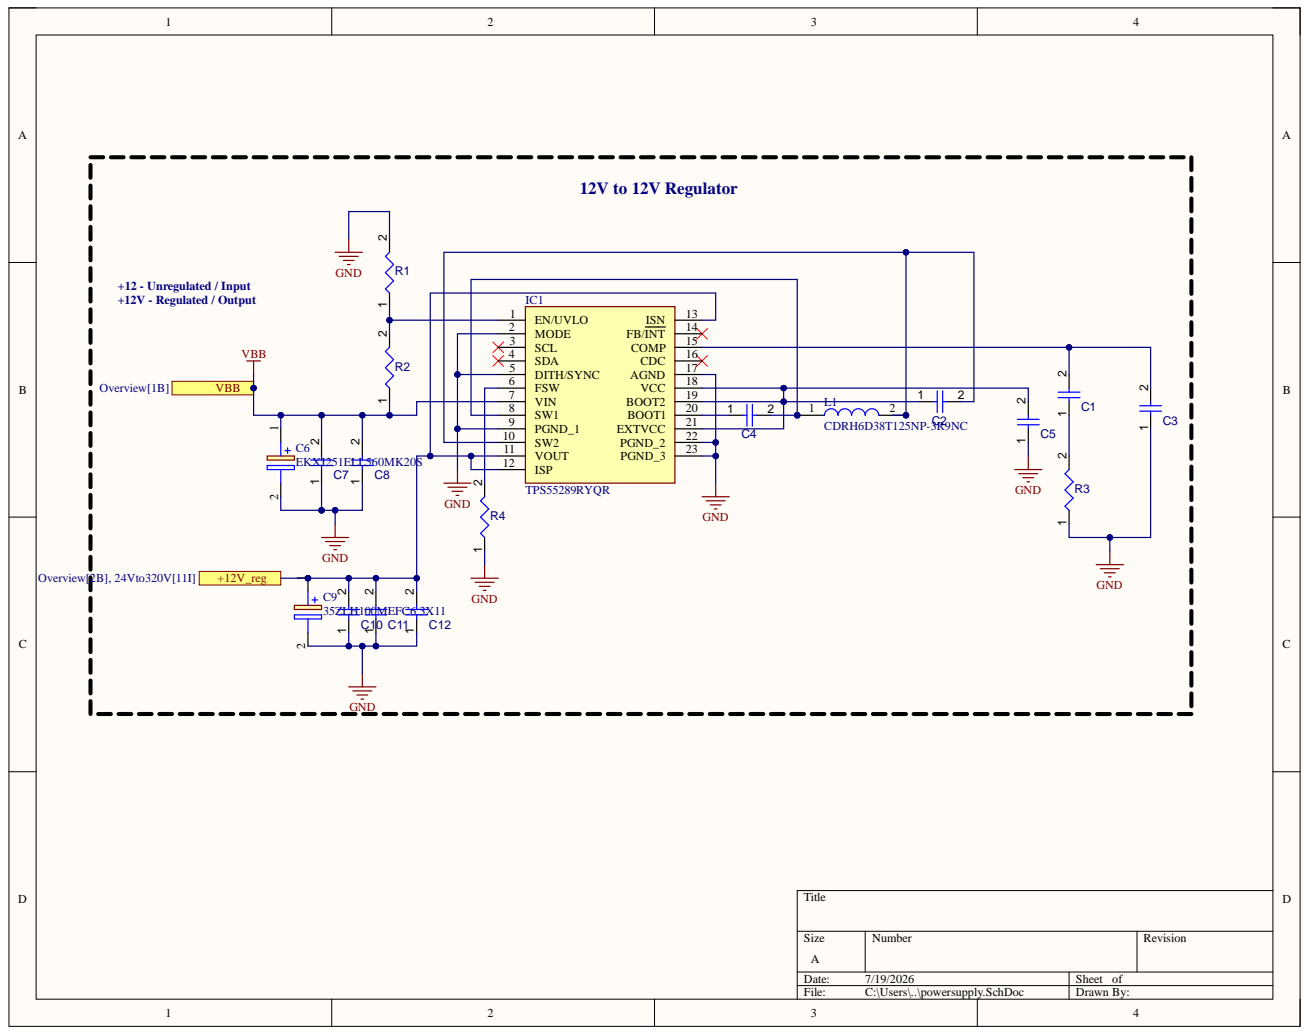
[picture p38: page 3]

1 1
T P G N P 12 IS

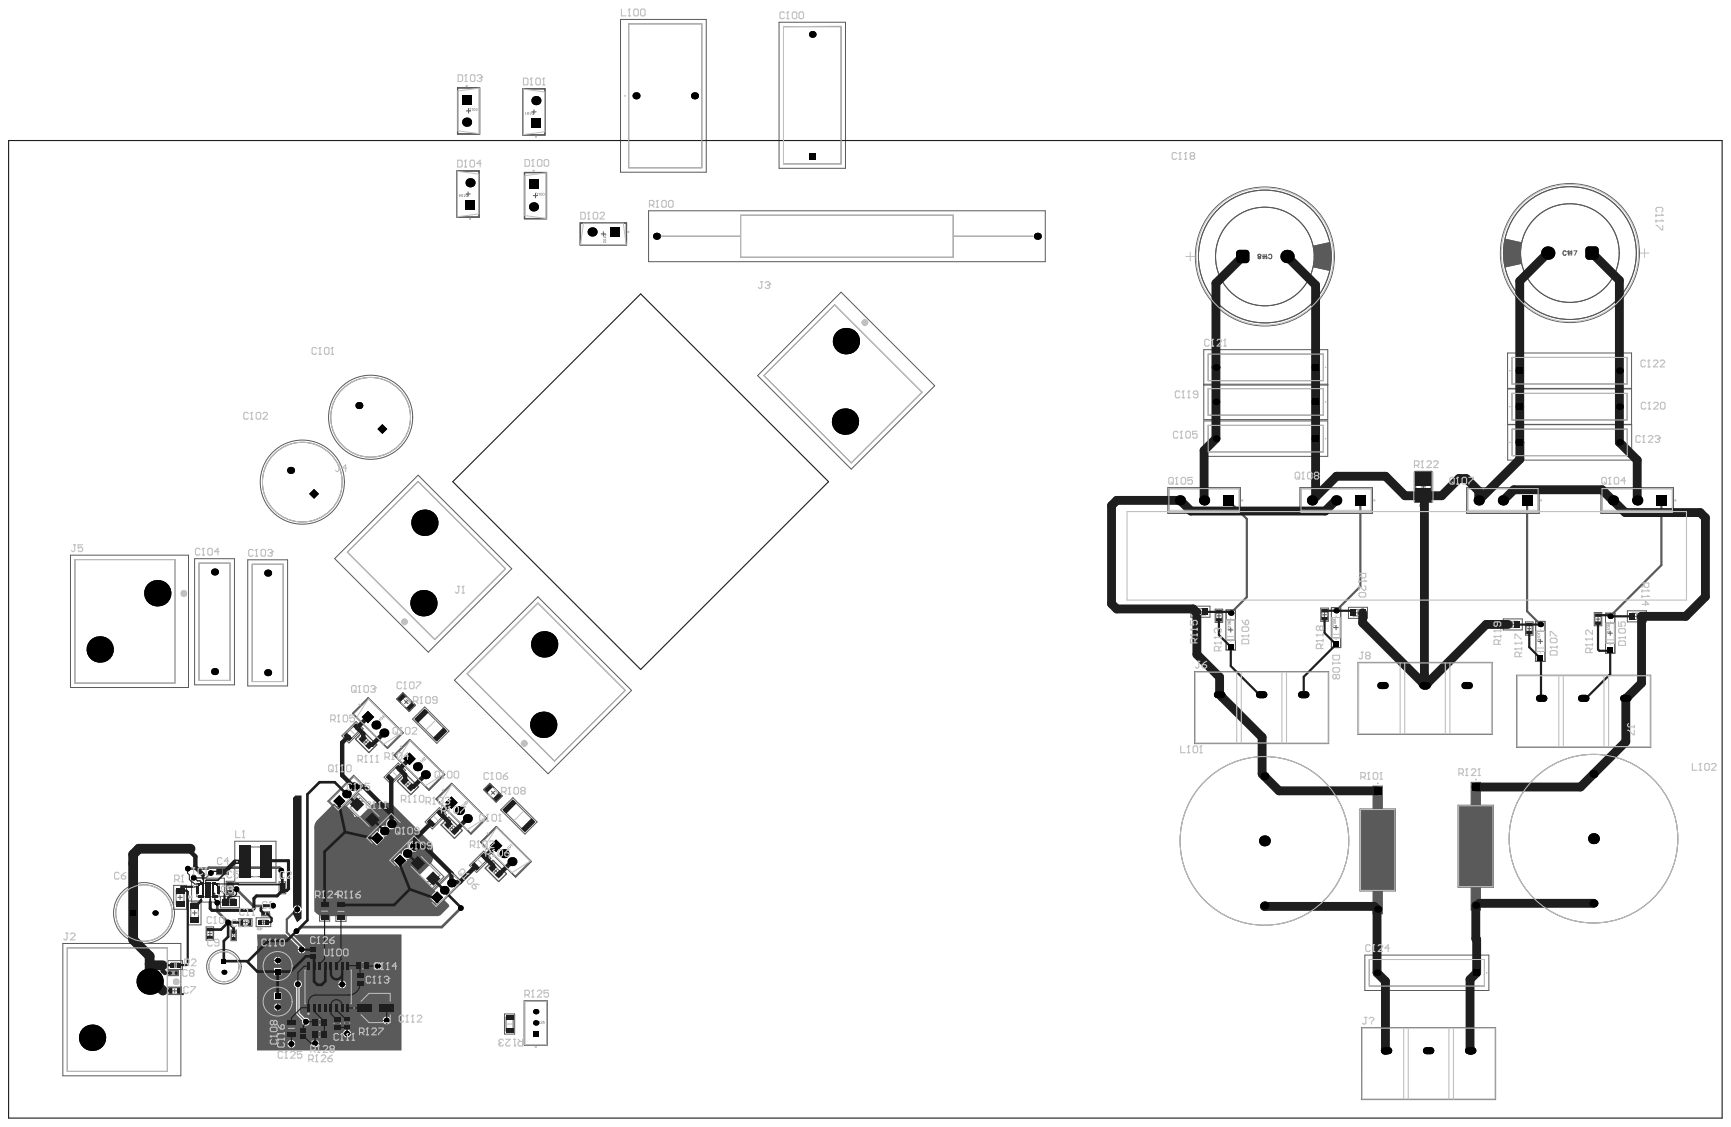
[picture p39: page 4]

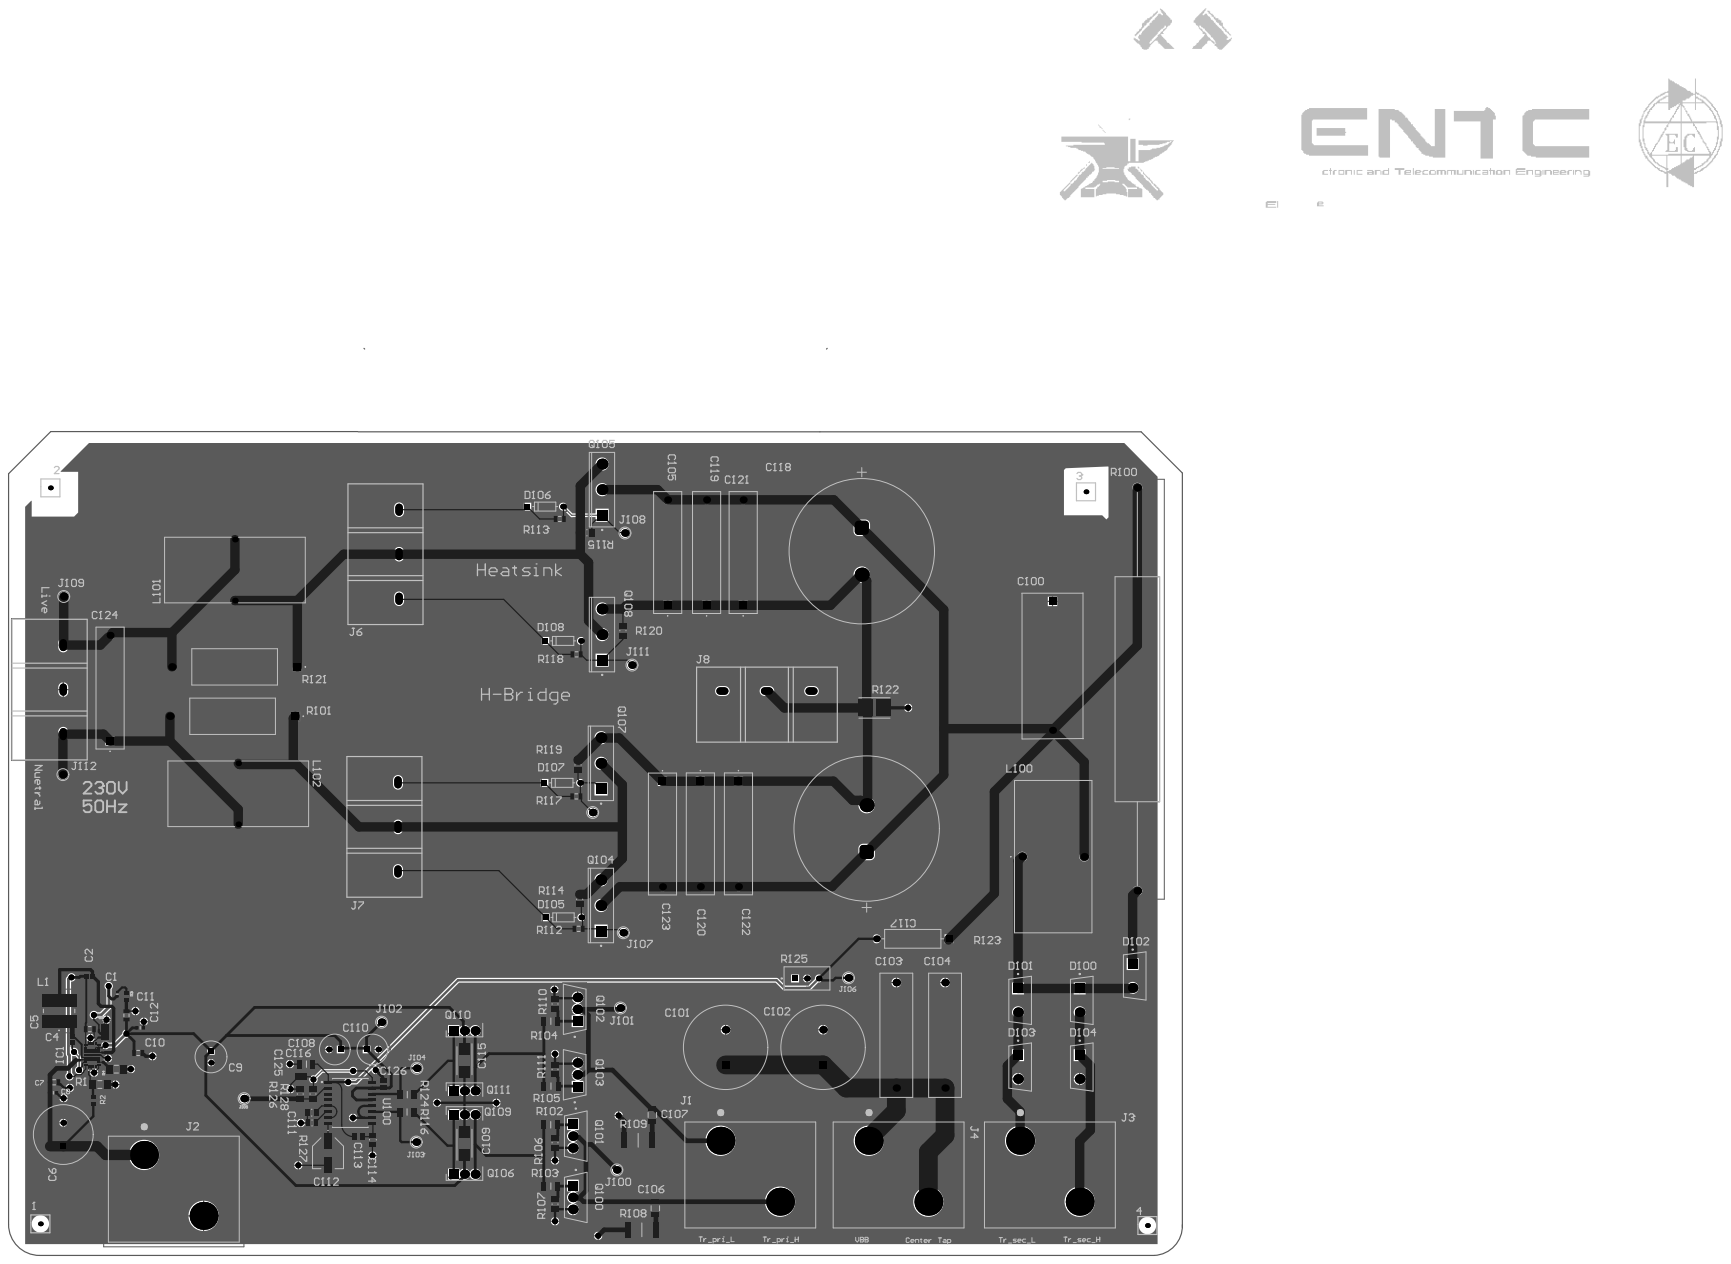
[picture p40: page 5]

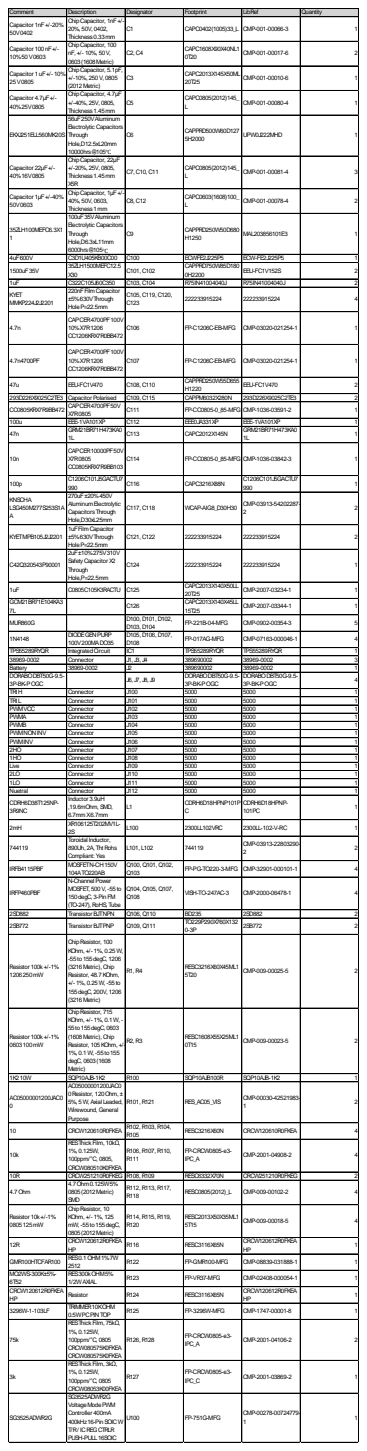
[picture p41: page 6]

Capacitor 100nF+/-10%50V0603 | ChipCapacitor, 100 nF, +/- 10%, 50V, 0603(1608Metric) | C2, C4 | CAPC1608X90X40NL1 0T20 | CMP-001-00017-6 | 2

Capacitor 1uF+/- 10% 25V0805 | ChipCapacitor, 5.1pF, +/-10%, 250V, 0805 (2012Metric) | C3 | CAPC2013X145X50ML 20T25 | CMP-001-00010-6 | 1

Capacitor 4.7µF+/-40%25V0805 | ChipCapacitor, 4.7µF +/-40%, 25V, 0805, Thickness1.45mm | C5 | CAPC0805(2012)145_ L | CMP-001-00080-4 | 1

EKXJ251ELL560MK20S | 56uF250VAluminum Electrolytic Capacitors Through Hole,D12.5xL20mm 10000hrs@105℃ | C6 | CAPPRD500W60D127 5H2000 | UPW0J222MHD | 1

Capacitor 22µF+/-40%16V0805 | ChipCapacitor, 22µF +/-20%, 25V, 0805, Thickness1.45mm X5R | C7, C10, C11 | CAPC0805(2012)145_ L | CMP-001-00081-4 | 3

Capacitor 1µF+/-40% 50V0603 | ChipCapacitor, 1µF+/-40%, 50V, 0603, Thickness1mm | C8, C12 | CAPC0603(1608)100_ L | CMP-001-00078-4 | 2

35ZLH100MEFC6.3X1 1 | 100uF35VAluminum Electrolytic Capacitors Through Hole,D6.3xL11mm 6000hrs@105℃ | C9 | CAPPRD250W50D680 H1250 | MAL203856101E3 | 1

4uF600V | C3D1U405KB00C00 | C100 | ECWFE2J225P5 | ECW-FE2J225P5 | 1
1500uF35V | 35ZLH1500MEFC12.5 X30 | C101, C102 | CAPPRD750W85D180 0H2200 | EEU-FC1V152S | 2

1uF | C322C105J60C350 | C103, C104 | R75IN41004040J | R75IN41004040J | 2
KYET MMKP224J2J2201 | 220nFFilm Capacitor ±5%630VThrough HoleP=22.5mm | C105, C119, C120, C123 | 222233915224 | 222233915224 | 4

4.7n | CAPCER4700PF100V 10%X7R1206 CC1206KRX7R0BB472 | C106 | FP-C1206C-EB-MFG | CMP-03020-021254-1 | 1

4.7n4700PF | CAPCER4700PF100V 10%X7R1206 CC1206KRX7R0BB472 | C107 | FP-C1206C-EB-MFG | CMP-03020-021254-1 | 1

47u | EEU-FC1V470 | C108, C110 | CAPPRD250W55D655 H1220 | EEU-FC1V470 | 2

293D226X9025C2TE3 | Capacitor Polarised | C109, C115 | CAPPM6032X280N | 293D226X9025C2TE3 | 2
CC0805KRX7R9BB472 | CAPCER4700PF50V X7R0805 | C111 | FP-CC0805-0_85-MFG | CMP-1036-03591-2 | 1

100u | EEE-1VA101XP | C112 | EEE0JA331XP | EEE-1VA101XP | 1
47n | GRM21BR71H473KA0 1L | C113 | CAPC2012X145N | GRM21BR71H473KA0 1L | 1
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

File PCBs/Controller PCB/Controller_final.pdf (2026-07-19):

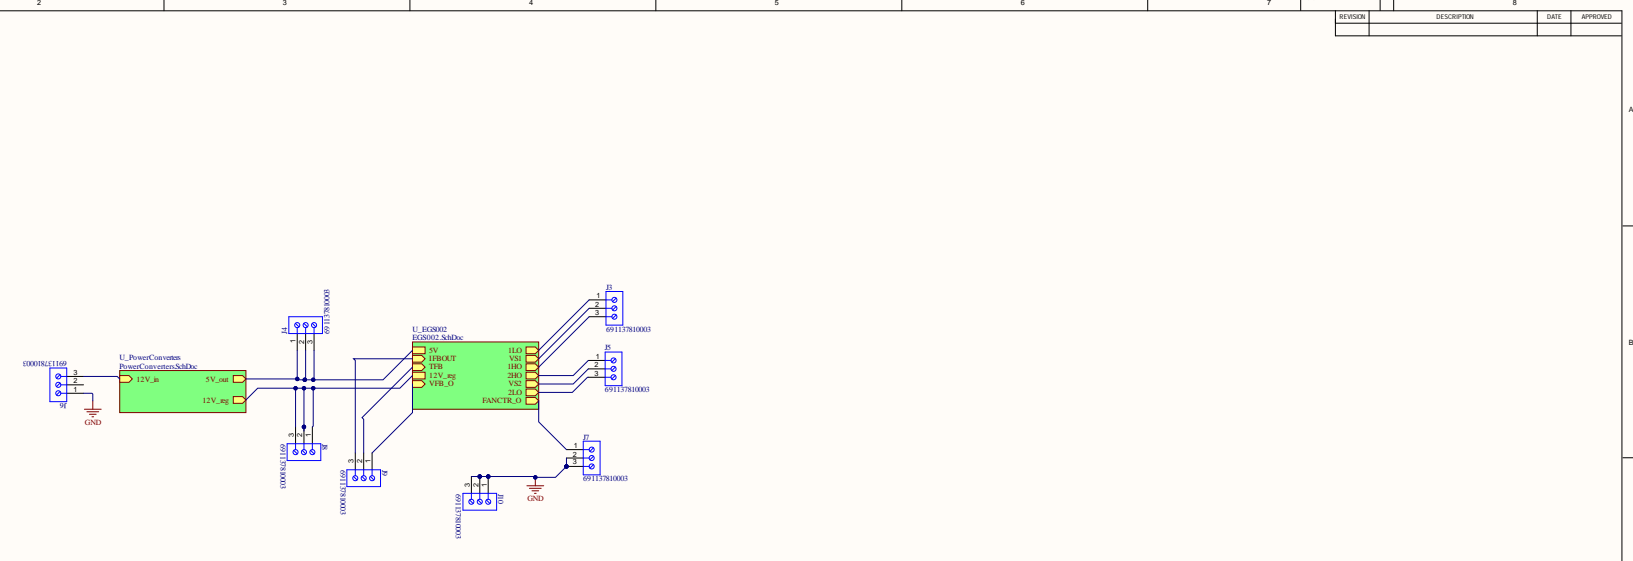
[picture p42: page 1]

T H I S D O C U M E N T A N D T H E D ATA D I S C L O S E D H E R E I N O R H E R E W I T H I S T H E P R O P E R T Y O F A LT I U M L I M I T E D A N D M AY B E F R E E LY D I S T R I B U T E D I N W H O L E . N O R I G H T S A R E R E S E R V E D O R E X P R E S S O R I M P L I E D W A R A N T E E G I V E N . | | REVISI ON | DESC R IPT I ON | DAT E | APPROVE D

C | ADWG NO: REV: C

A P P R O VA L S | D AT E | P R OJE CT | ****

E N G : **
C H K : * | | T I T L E *

D S N : | | P R OJE C T R E V I S I O N : a 4 a a a 0 | D O C U M E N T R E V I S I O N : 8 5 9 f 3 a 9 5 2 1 1 5 1 a 7 b461 a5ec63ddf1004f | D E S I G N I T E M : eaea222abc958451 29cb d 6 f 4 7 1 c 2 2 3 8 | a

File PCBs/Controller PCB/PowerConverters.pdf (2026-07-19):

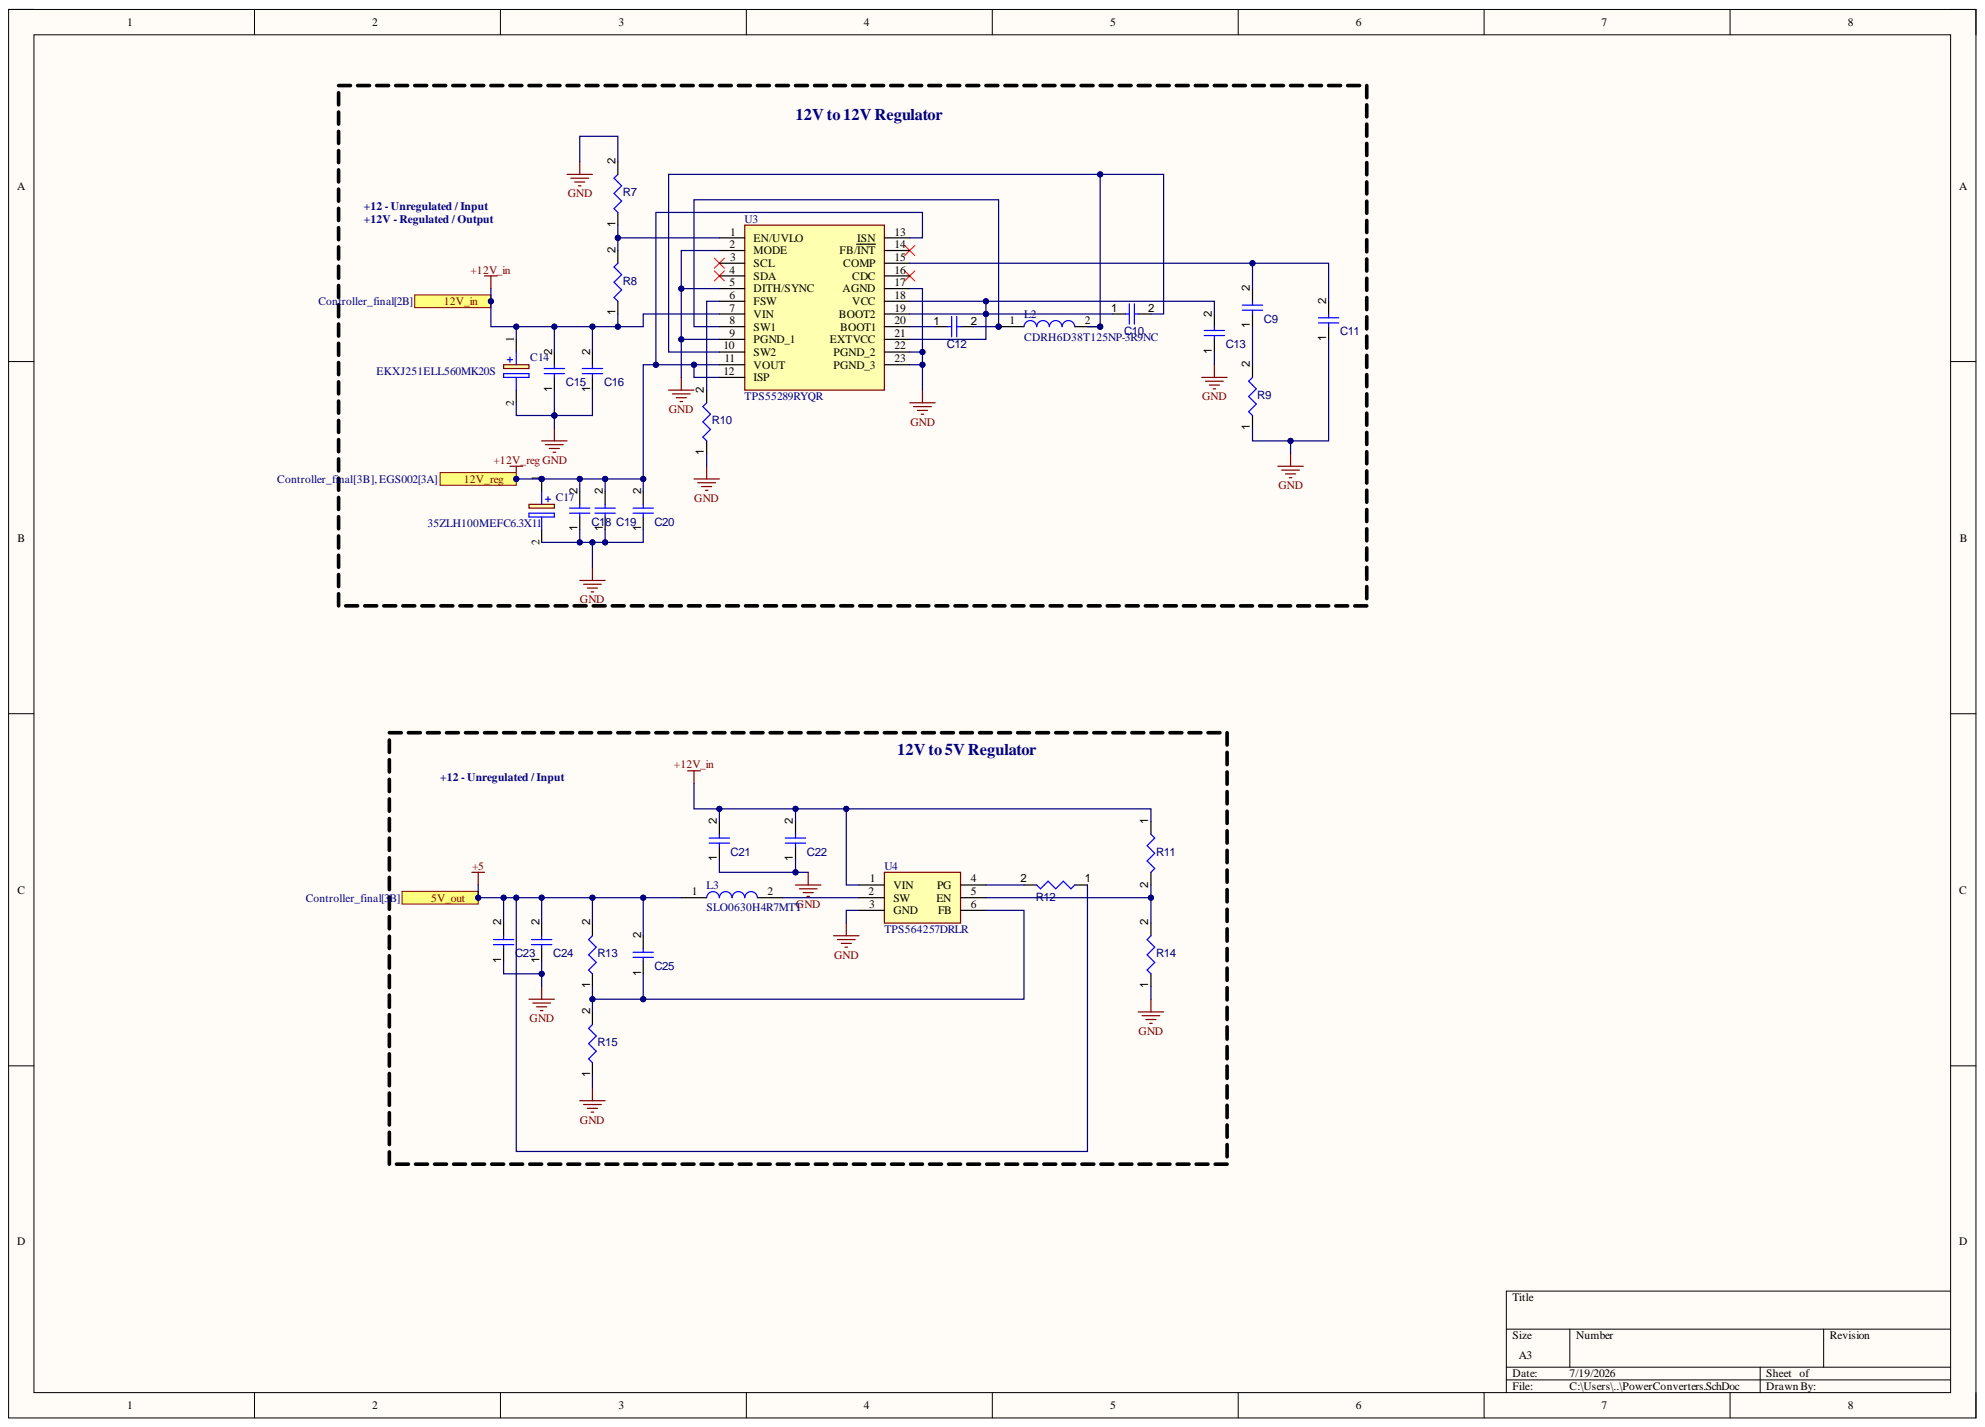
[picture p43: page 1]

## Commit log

2026-07-19 Added PCB files
    [24Vto12V.SchDoc, 24Vto320V.SchDoc, 24Vto5V.SchDoc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]
2026-07-19 Added Enclosure Files
    [forge_bottom.SLDPRT, pcb_mounts.SLDPRT, top_lid.SLDPRT]
